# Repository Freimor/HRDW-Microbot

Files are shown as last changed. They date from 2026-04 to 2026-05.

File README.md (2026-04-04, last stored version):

# Robot Library for ESP32S3-N16R8

Библиотека функций для робота на базе микроконтроллера **ESP32S3-N16R8**.

## Компоненты

| Компонент | Модель | Интерфейс |
|---|---|---|
| Микроконтроллер | ESP32S3-N16R8 | - |
| Камера | OV5640 (DFRobot AI CAM) | DVP |
| Монитор батареи | LC709203F | I2C |
| АЦП для фоторезисторов | ADS1015 | I2C |
| Фоторезисторы | 4 шт | ADS1015 |
| Датчики линии | GP25700 (4 шт) | GPIO |
| Контроллер двигателей | DRV8834 | PWM + DIR |
| Энкодеры | OH137 (2 шт) | GPIO Interrupt |
| TOF дальномер | VL53L0X | I2C |
| Датчик освещенности | LTR-308 | I2C |
| Адресные светодиоды | SK6812 (4 шт) | GPIO |
| Buzzer | Пьезо | PWM |

## Структура проекта

```
robot-library/
├── include/
│   ├── robot_config.h      # Конфигурация пинов
│   └── robot_library.h     # Заголовочный файл библиотеки
├── src/
│   └── robot_library.cpp   # Реализация библиотеки
├── examples/
│   └── basic_example.ino   # Пример использования
└── README.md               # Этот файл
```

## Установка

1. Скопируйте папки `include` и `src` в ваш проект Arduino/PlatformIO
2. Для PlatformIO добавьте в `platformio.ini`:
   ```ini
   lib_deps = 
       pololu/vl53l0x
   build_flags = 
       -D USE_ESP_CAMERA
   ```

## Быстрый старт

```cpp
#include "robot_library.h"

void setup() {
    // Инициализация всех компонентов
    robot.begin();
}

void loop() {
    // Чтение датчиков
    float voltage = robot.getBatteryVoltage();
    uint16_t distance = robot.getDistanceMM();
    float lux = robot.getLux();
    
    // Управление двигателями
    robot.setMotorSpeed(100, 100); // Левый, Правый (-255 до 255)
    
    // Светодиоды
    robot.setAllLedsColor(255, 0, 0); // Красный цвет
    robot.showLeds();
    
    delay(1000);
}
```

## API Библиотеки

### Инициализация
- `bool begin()` - Инициализация всех компонентов

### Батарея (LC709203F)
- `float getBatteryVoltage()` - Напряжение батареи (В)
- `float getBatteryPercentage()` - Процент заряда (%)
- `bool isCharging()` - Статус зарядки

### Фоторезисторы (ADS1015)
- `PhotoResistorData getPhotoResistorData()` - Данные со всех 4 каналов
- `uint16_t getPhotoResistorValue(uint8_t channel)` - Значение канала (0-3)

### Датчики линии (GP25700)
- `LineSensorData getLineSensorData()` - Данные со всех датчиков
- `bool getLineSensorValue(uint8_t sensorNum)` - Значение датчика (1-4)
- `uint8_t getLinePosition()` - Позиция линии (0-3 или 255 если нет)

### Двигатели (DRV8834) + Энкодеры (OH137)
- `void setMotorSpeed(int16_t left, int16_t right)` - Установка скорости
- `void setLeftMotorSpeed(int16_t speed)` - Скорость левого мотора
- `void setRightMotorSpeed(int16_t speed)` - Скорость правого мотора
- `void stopMotors()` - Остановка двигателей
- `int32_t getLeftEncoderCount()` - Позиция левого энкодера
- `int32_t getRightEncoderCount()` - Позиция правого энкодера
- `void resetEncoders()` - Сброс энкодеров

### TOF дальномер (VL53L0X)
- `uint16_t getDistanceMM()` - Расстояние в мм
- `bool isDistanceValid()` - Валидность данных

### Датчик освещенности (LTR-308)
- `float getLux()` - Освещенность в Lux
- `bool isLightValid()` - Валидность данных

### Светодиоды (SK6812)
- `void setLedColor(uint8_t index, uint8_t r, uint8_t g, uint8_t b)` - Цвет светодиода
- `void setAllLedsColor(uint8_t r, uint8_t g, uint8_t b)` - Цвет всех светодиодов
- `void clearLeds()` - Выключить все
- `void showLeds()` - Обновить ленту
- `void setLedBrightness(uint8_t brightness)` - Яркость (0-255)

### Buzzer
- `void beep(uint16_t frequency, uint16_t duration_ms)` - Короткий сигнал
- `void playTone(uint16_t frequency, uint16_t duration_ms)` - Воспроизведение тона
- `void stopBuzzer()` - Остановить звук

### Камера (OV5640)
- `bool cameraInit()` - Инициализация камеры
- `bool cameraCapture()` - Захват кадра
- `void cameraDeinit()` - Деинициализация

## Конфигурация пинов

Пины настроены в файле `robot_config.h`. При необходимости измените под вашу схему.

## Зависимости

- **Arduino ESP32 Core** - базовая платформа
- **Wire.h** - I2C коммуникация (входит в core)
- **Pololu VL53L0X Library** (опционально) - для улучшенной работы TOF

## Лицензия

MIT License

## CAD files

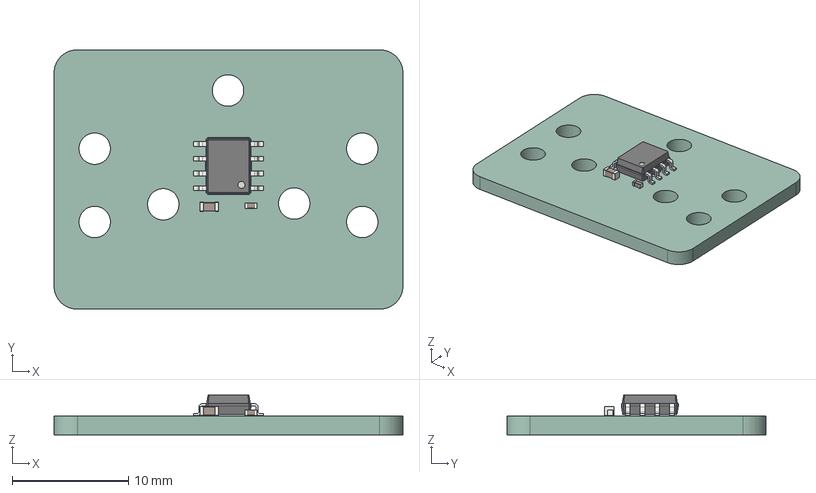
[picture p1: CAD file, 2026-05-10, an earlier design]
Old_versions/Microbot_v1/BLDC_encoder_pcb(2024-11-29_155120).step
30.0 x 22.3 x 3.40 mm
C_0603_1608Metric
SOIC_8_39x49mm_P127mm
C_0402_1005Metric
BLDC_encoder_pcb_PCB

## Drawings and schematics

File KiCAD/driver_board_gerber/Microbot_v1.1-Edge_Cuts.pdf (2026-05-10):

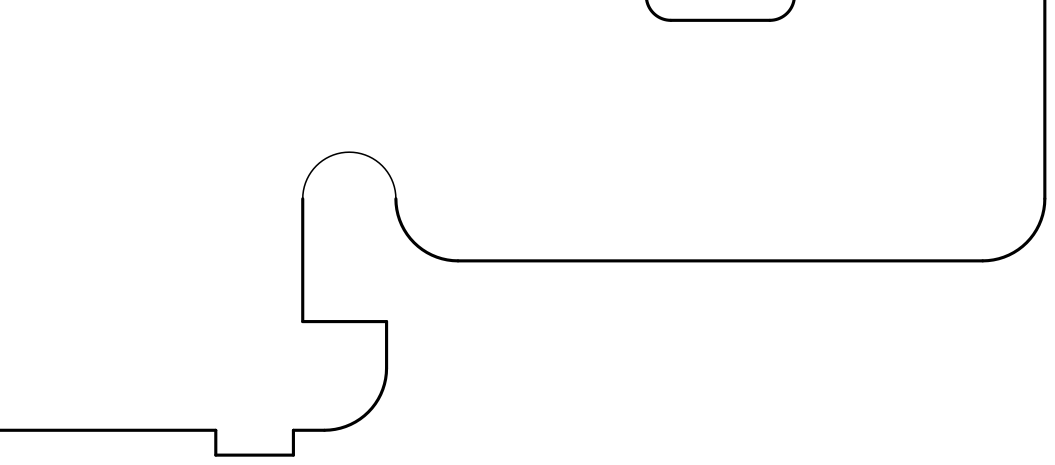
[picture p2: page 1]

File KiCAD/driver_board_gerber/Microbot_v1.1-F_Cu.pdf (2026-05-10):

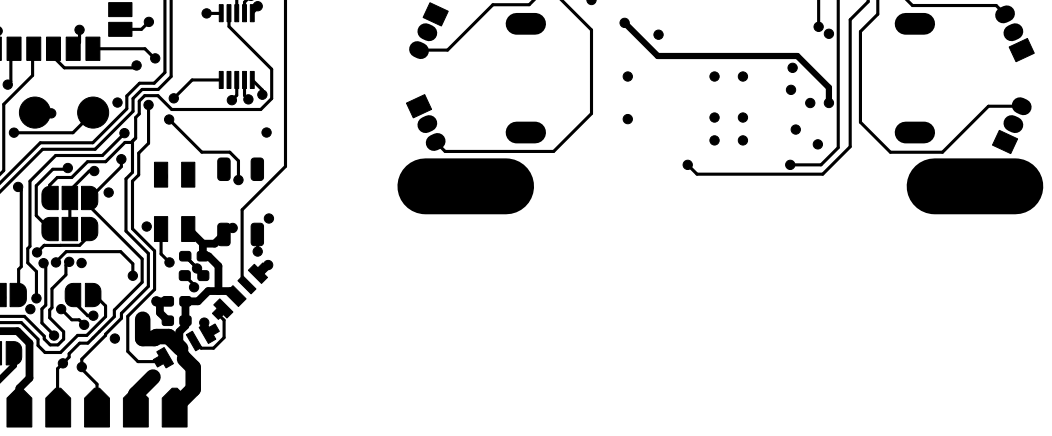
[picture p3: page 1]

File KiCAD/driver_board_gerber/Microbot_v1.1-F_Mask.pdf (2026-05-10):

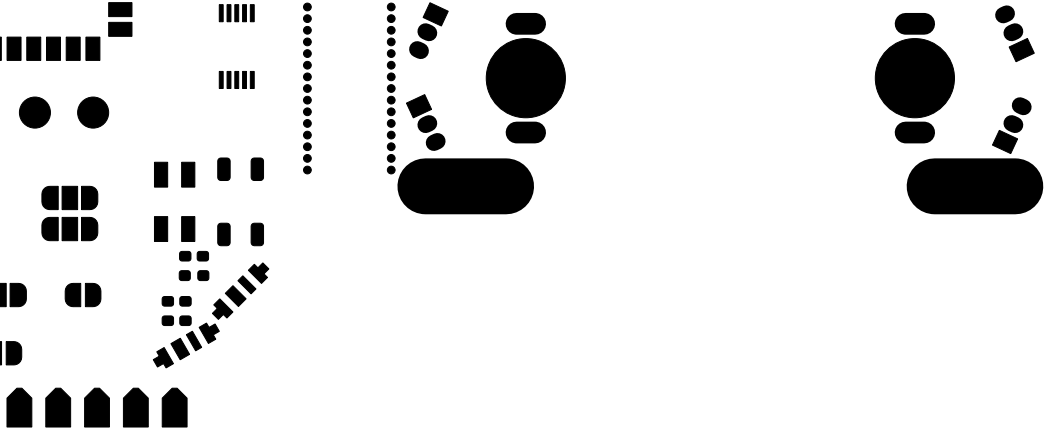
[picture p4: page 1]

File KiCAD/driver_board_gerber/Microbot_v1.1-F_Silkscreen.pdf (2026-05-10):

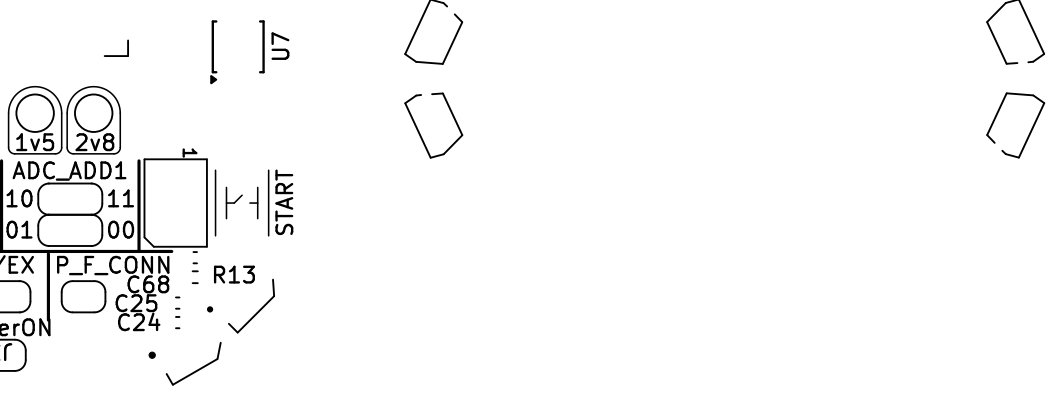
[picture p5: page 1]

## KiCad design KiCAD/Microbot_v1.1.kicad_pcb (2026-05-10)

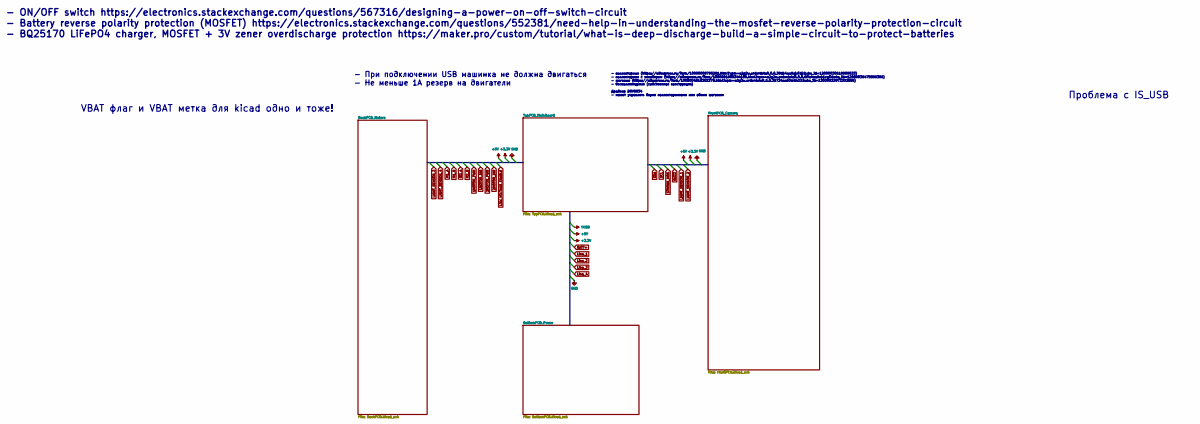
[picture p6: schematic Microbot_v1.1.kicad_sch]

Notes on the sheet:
- При подключении USB машинка не должна двигаться - Не меньше 1А резерв на двигатели
- ON/OFF switch https://electronics.stackexchange.com/questions/567316/designing-a-power-on-off-switch-circuit - Battery reverse polarity protection (MOSFET) https://electronics.stackexchange.com/questions/552381/need-help-in-understanding-the-mosfet-reverse-polarity-protection-circuit - BQ25170 Li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
Проблема с IS_USB
- коллекторные (https://aliexpress.ru/item/10000008795281.html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) - коллекторные с энкодером (https://aliexpress.ru/item/1005001608344100.html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) - шаговые (https://aliexp…
VBAT флаг и VBAT метка для kicad одно и тоже!

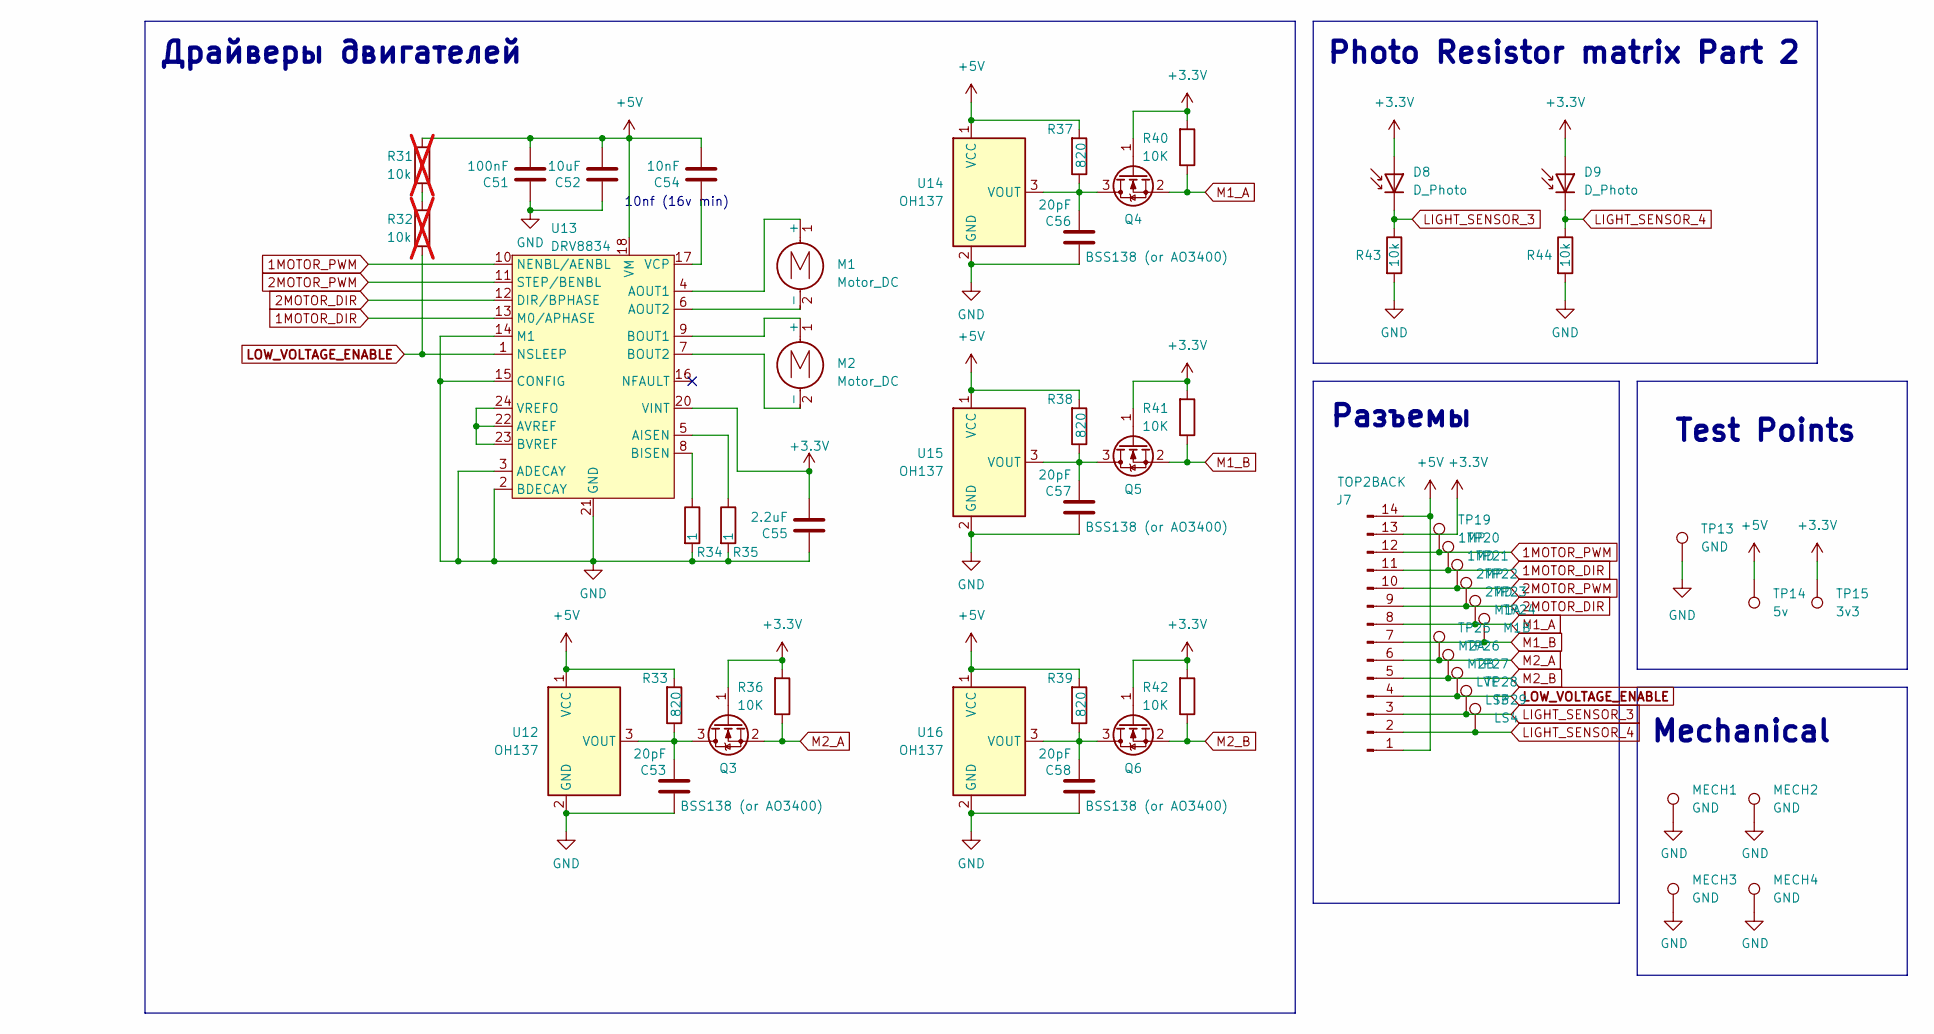
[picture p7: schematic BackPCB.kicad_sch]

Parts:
C51: 100nF; C_0402_1005Metric_Pad0.74x0.62mm_HandSolder
C52: 10uF; C_0603_1608Metric_Pad1.08x0.95mm_HandSolder
C53, C56, C57, C58: 20pF; C_0603_1608Metric_Pad1.08x0.95mm_HandSolder
C54: 10nF; C_0402_1005Metric_Pad0.74x0.62mm_HandSolder
C55: 2.2uF; C_0603_1608Metric_Pad1.08x0.95mm_HandSolder
D8, D9: D_Photo; Photoresistor_TH_Vertical
J7: TOP2BACK; CONN_14pin
M1, M2: Motor_DC; GW12-N20 with encoders PCB footprint
MECH1, MECH2, MECH3, MECH4: GND; CONN_PCB2PCB
Q3, Q4, Q5, Q6: BSS138 (or AO3400); SOT-23
R31, R32: 10k; R_0402_1005Metric_Pad0.72x0.64mm_HandSolder; not fitted
R33, R37, R38, R39: 820; R_0402_1005Metric_Pad0.72x0.64mm_HandSolder
R34, R35: 1; R_1206_3216Metric_Pad1.30x1.75mm_HandSolder
R36, R40, R41, R42: 10K; R_0402_1005Metric_Pad0.72x0.64mm_HandSolder
R43, R44: 10k; R_0402_1005Metric_Pad0.72x0.64mm_HandSolder
TP13: GND; TestPoint_Pad_D2.0mm
TP14: 5v; TestPoint_Pad_D2.0mm
TP15: 3v3; TestPoint_Pad_D2.0mm
TP19: 1MP; TestPoint_Pad_D1.0mm
TP20: 1MD; TestPoint_Pad_D1.0mm
TP21: 2MP; TestPoint_Pad_D1.0mm
TP22: 2MD; TestPoint_Pad_D1.0mm
TP23: M1A; TestPoint_Pad_D1.0mm
TP24: M1B; TestPoint_Pad_D1.0mm
TP25: M2A; TestPoint_Pad_D1.0mm
TP26: M2B; TestPoint_Pad_D1.0mm
TP27: LVE; TestPoint_Pad_D1.0mm
TP28: LS3; TestPoint_Pad_D1.0mm
TP29: LS4; TestPoint_Pad_D1.0mm
U12, U14, U15, U16: OH137; TO-92S
U13: DRV8834; HTSSOP-24-1EP_4.4x7.8mm_P0.65mm_EP3.4x7.8mm_Mask2.4x2.98mm

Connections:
1MOTOR_DIR: J7.11, TP20.1, U13.13 (M0/APHASE); also elsewhere on the board
1MOTOR_PWM: J7.12, TP19.1, U13.10 (NENBL/AENBL); also elsewhere on the board
2MOTOR_DIR: J7.9, TP22.1, U13.12 (DIR/BPHASE); also elsewhere on the board
2MOTOR_PWM: J7.10, TP21.1, U13.11 (STEP/BENBL); also elsewhere on the board
+3.3V: C55.2, D8.2 (A), D9.2 (A), J7.13, Q3.1 (G), Q4.1 (G), Q5.1 (G), Q6.1 (G), R36.2, R40.2, R41.2, R42.2, TP15.1, U13.20 (VINT); also elsewhere on the board
+5V: C51.2, C52.2, C54.2, J7.1, J7.14, R31.1, R33.2, R37.2, R38.2, R39.2, TP14.1, U12.1 (VCC), U13.18 (VM), U13.19 (VM), U14.1 (VCC), U15.1 (VCC), U16.1 (VCC); also elsewhere on the board
GND: C51.1, C52.1, C53.1, C55.1, C56.1, C57.1, C58.1, MECH1.1, MECH2.1, MECH3.1, MECH4.1, R34.2, R35.2, R43.2, R44.2, TP13.1, U12.2 (GND), U13.2 (BDECAY), U13.3 (ADECAY), U13.14 (M1), U13.15 (CONFIG), U13.21 (GND), U13.25, U14.2 (GND), U15.2 (GND), U16.2 (GND); also elsewhere on the board
LIGHT_SENSOR_3: D8.1 (K), J7.3, R43.1, TP28.1; also elsewhere on the board
LIGHT_SENSOR_4: D9.1 (K), J7.2, R44.1, TP29.1; also elsewhere on the board
LOW_VOLTAGE_ENABLE: J7.4, R32.2, TP27.1, U13.1 (NSLEEP); also elsewhere on the board
M1_A: J7.8, Q4.2 (S), R40.1, TP23.1; also elsewhere on the board
M1_B: J7.7, Q5.2 (S), R41.1, TP24.1; also elsewhere on the board
M2_A: J7.6, Q3.2 (S), R36.1, TP25.1; also elsewhere on the board
M2_B: J7.5, Q6.2 (S), R42.1, TP26.1; also elsewhere on the board
unnamed: M2.1 (+), U13.9 (BOUT1)
unnamed: M2.2 (-), U13.7 (BOUT2)
unnamed: C53.2, Q3.3 (D), R33.1, U12.3 (VOUT)
unnamed: C56.2, Q4.3 (D), R37.1, U14.3 (VOUT)
unnamed: C57.2, Q5.3 (D), R38.1, U15.3 (VOUT)
unnamed: C58.2, Q6.3 (D), R39.1, U16.3 (VOUT)
unnamed: R31.2, R32.1
unnamed: R35.1, U13.5 (AISEN)
unnamed: U13.22 (AVREF), U13.23 (BVREF), U13.24 (VREFO)
unnamed: R34.1, U13.8 (BISEN)
unnamed: C54.1, U13.17 (VCP)

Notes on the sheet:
10nf (16v min)
Photo Resistor matrix Part 2
Mechanical
Test Points
Драйверы двигателей
Разъемы

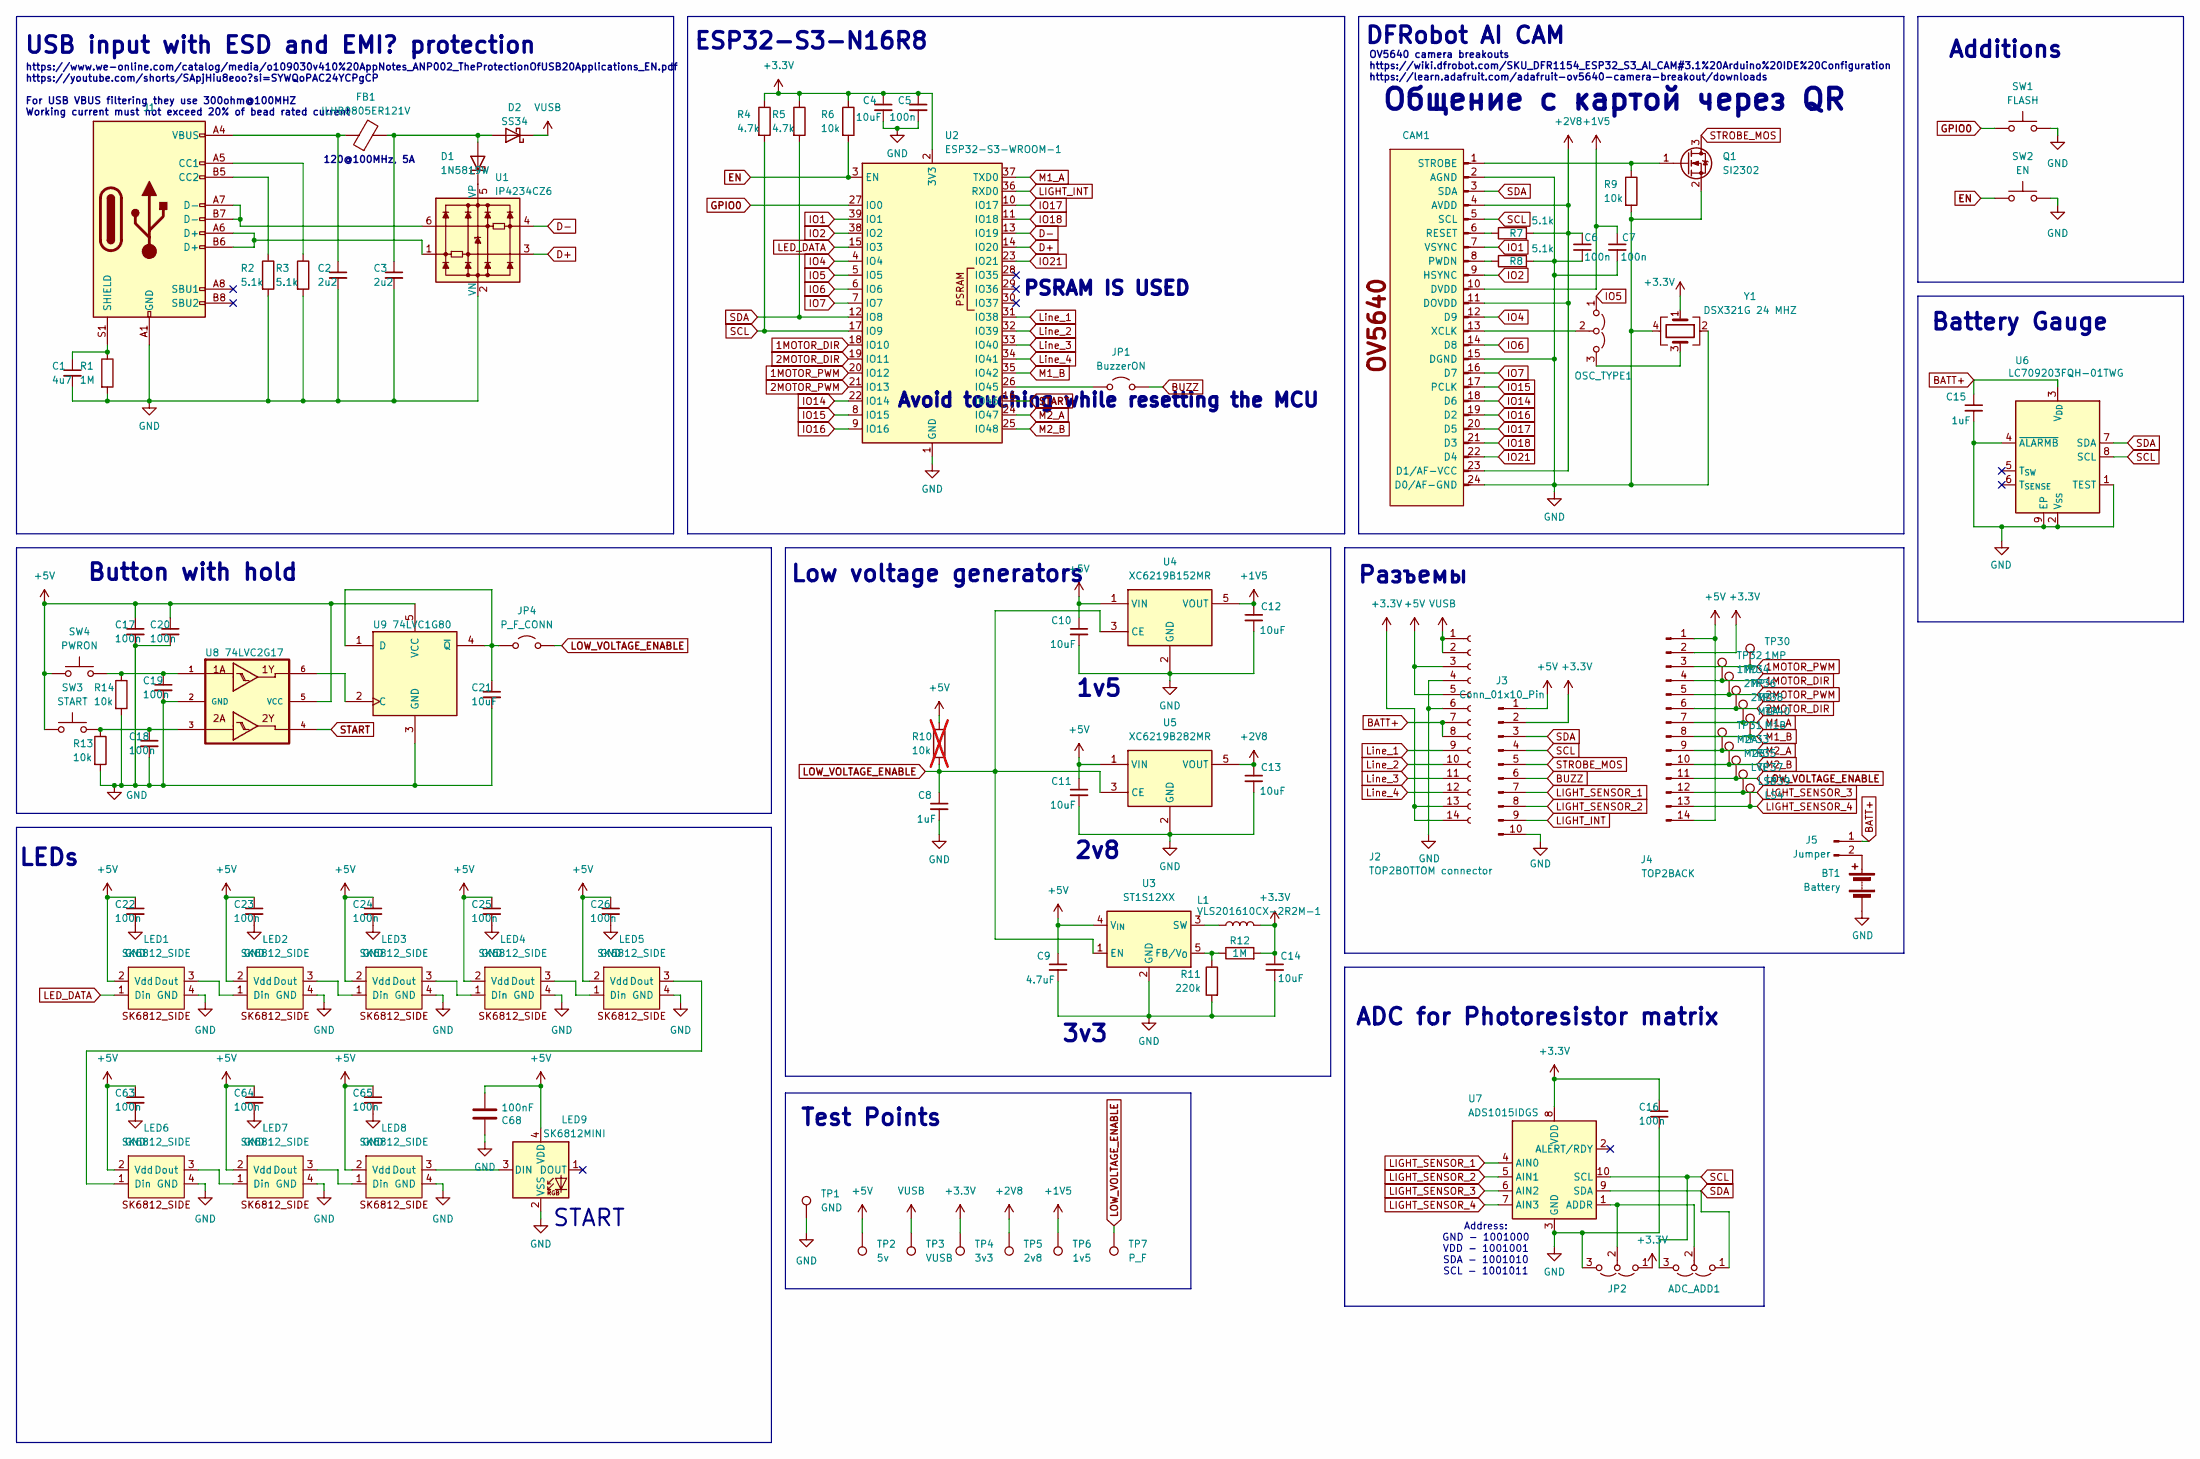
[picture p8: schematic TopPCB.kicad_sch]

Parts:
ADC_ADD1: Jumper_3_Open; SolderJumper-3_P1.3mm_Open_RoundedPad1.0x1.5mm_NumberLabels
BT1: Battery; Conn_Molex_2026560021(Pico-EZmate_Slim)
C1: 4u7; C_0603_1608Metric_Pad1.08x0.95mm_HandSolder
C2, C3: 2u2; C_0603_1608Metric_Pad1.08x0.95mm_HandSolder
C4, C21: 10uF; C_0603_1608Metric
C5, C6, C7, C16, C17, C18, C19, C20, C22, C23, C24, C25, C26, C63, C64, C65: 100n; C_0402_1005Metric_Pad0.74x0.62mm_HandSolder
C8, C15: 1uF; C_0603_1608Metric_Pad1.08x0.95mm_HandSolder
C9: 4.7uF; C_0603_1608Metric_Pad1.08x0.95mm_HandSolder
C10, C11, C12, C13, C14: 10uF; C_0603_1608Metric_Pad1.08x0.95mm_HandSolder
C68: 100nF; C_0402_1005Metric_Pad0.74x0.62mm_HandSolder
CAM1: OV5640; CAM_OV5640_OMRON_XF2M-2415-1A
D1: 1N5819W; D_SOD-123
D2: SS34; D_SMA_Handsoldering
FB1: ILHB0805ER121V; L_0805_2012Metric_Pad1.15x1.40mm_HandSolder
J1: USB_C_Receptacle_USB2.0; RUICHI_TYPE-C-16PF-020
J2: TOP2BOTTOM connector; PinHeader_2x07_P2.54mm_Vertical_SMD
J3: Conn_01x10_Pin; CONN_10pin
J4: TOP2BACK; CONN_14pin
J5: Jumper; PinHeader_1x02_P2.54mm_Vertical
JP1: BuzzerON; SolderJumper-2_P1.3mm_Open_RoundedPad1.0x1.5mm
JP2: Jumper_3_Open; SolderJumper-3_P1.3mm_Open_RoundedPad1.0x1.5mm_NumberLabels
JP4: P_F_CONN; SolderJumper-2_P1.3mm_Open_RoundedPad1.0x1.5mm
L1: VLS201610CX-2R2M-1; IND_VLS201610CX-220M-1
LED1, LED2, LED3, LED4, LED5, LED6, LED7, LED8: SK6812_SIDE; ADR_LED_SK6812_SIDE
LED9: SK6812MINI; LED_SK6812MINI_PLCC4_3.5x3.5mm_P1.75mm
OSC_TYPE1: OSC_IN/EX; SolderJumper-3_P1.3mm_Open_RoundedPad1.0x1.5mm_NumberLabels
Q1: SI2302; SOT-23
R1, R12: 1M; R_0402_1005Metric_Pad0.72x0.64mm_HandSolder
R2, R3, R7, R8: 5.1k; R_0402_1005Metric_Pad0.72x0.64mm_HandSolder
R4, R5: 4.7k; R_0402_1005Metric_Pad0.72x0.64mm_HandSolder
R6, R9, R13, R14: 10k; R_0402_1005Metric_Pad0.72x0.64mm_HandSolder
R10: 10k; R_0402_1005Metric_Pad0.72x0.64mm_HandSolder; not fitted
R11: 220k; R_0402_1005Metric_Pad0.72x0.64mm_HandSolder
SW1: FLASH; SW_SMD_KLS7-TS3401
SW2: EN; SW_SMD_KLS7-TS3401
SW3: START; SW_SMD_KLS7-TS3401
SW4: PWRON; SW_SMD_KLS7-TS3401
TP1: GND; TestPoint_Pad_D2.0mm
TP2: 5v; TestPoint_Pad_D2.0mm
TP3: VUSB; TestPoint_Pad_D2.0mm
TP4: 3v3; TestPoint_Pad_D2.0mm
TP5: 2v8; TestPoint_Pad_D2.0mm
TP6: 1v5; TestPoint_Pad_D2.0mm
TP7: P_F; TestPoint_Pad_D2.0mm
TP30: 1MP; TestPoint_Pad_D1.0mm
TP31: M2A; TestPoint_Pad_D1.0mm
TP32: 1MD; TestPoint_Pad_D1.0mm
TP33: M2B; TestPoint_Pad_D1.0mm
TP34: 2MP; TestPoint_Pad_D1.0mm
TP35: LVE; TestPoint_Pad_D1.0mm
TP36: 2MD; TestPoint_Pad_D1.0mm
TP37: LS3; TestPoint_Pad_D1.0mm
TP38: M1A; TestPoint_Pad_D1.0mm
TP39: LS4; TestPoint_Pad_D1.0mm
TP40: M1B; TestPoint_Pad_D1.0mm
U1: IP4234CZ6; SC-74-6_1.55x2.9mm_P0.95mm
U2: ESP32-S3-WROOM-1
U3: ST1S12XX; TSOT-23-5
U4: XC6219B152MR; SOT-23-5
U5: XC6219B282MR; SOT-23-5
U6: LC709203FQH-01TWG; WDFN-8-1EP_4x3mm_P0.65mm_EP2.4x1.8mm
U7: ADS1015IDGS; TSSOP-10_3x3mm_P0.5mm
U8: 74LVC2G17; SOT-23-6_Handsoldering
U9: 74LVC1G80
Y1: DSX321G 24 MHZ; Crystal_SMD_3225-4Pin_3.2x2.5mm_HandSoldering

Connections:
1MOTOR_DIR: J4.4, TP32.1, U2.18 (IO10); also elsewhere on the board
1MOTOR_PWM: J4.3, TP30.1, U2.20 (IO12); also elsewhere on the board
2MOTOR_DIR: J4.6, TP36.1, U2.19 (IO11); also elsewhere on the board
2MOTOR_PWM: J4.5, TP34.1, U2.21 (IO13); also elsewhere on the board
+1V5: C7.1, C12.1, CAM1.10 (DVDD), TP6.1, U4.5 (VOUT)
+2V8: C6.1, C13.1, CAM1.4 (AVDD), CAM1.11 (DOVDD), CAM1.23 (D1/AF-VCC), R7.2, TP5.1, U5.5 (VOUT)
+3.3V: C4.1, C5.1, C14.1, C16.1, J2.13, J2.14, J3.2, J4.2, JP2.1 (A), L1.2, R4.1, R5.1, R6.1, R12.2, TP4.1, U2.2 (3V3), U7.8 (VDD), Y1.1; also elsewhere on the board
+5V: C9.1, C10.1, C11.1, C17.1, C20.1, C22.1, C23.1, C24.1, C25.1, C26.1, C63.1, C64.1, C65.1, C68.2, J2.3, J2.5, J3.1, J4.1, J4.14, LED1.2 (Vdd), LED2.2 (Vdd), LED3.2 (Vdd), LED4.2 (Vdd), LED5.2 (Vdd), LED6.2 (Vdd), LED7.2 (Vdd), LED8.2 (Vdd), LED9.4 (VDD), R10.1, SW3.1, SW4.1, TP2.1, U3.4 (V_{IN}), U4.1 (VIN), U5.1 (VIN), U8.5 (VCC), U9.5 (VCC); also elsewhere on the board
BATT+: C15.1, J2.7, J2.8, J5.1, U6.3 (V_{DD}); also elsewhere on the board
BUZZ: J3.6, JP1.2 (B); also elsewhere on the board
D+: U1.3, U2.14 (IO20)
D-: U1.4, U2.13 (IO19)
EN: R6.2, SW2.1, U2.3 (EN)
GND: BT1.2 (-), C1.2, C2.2, C3.2, C4.2, C5.2, C6.2, C7.2, C8.2, C9.2, C10.2, C11.2, C12.2, C13.2, C14.2, C15.2, C16.2, C17.2, C18.2, C19.2, C20.2, C21.2, C22.2, C23.2, C24.2, C25.2, C26.2, C63.2, C64.2, C65.2, C68.1, CAM1.2 (AGND), CAM1.15 (DGND), CAM1.24 (D0/AF-GND), CAM1.P1, CAM1.P2, J1.A1 (GND), J1.A12 (GND), J1.B1 (GND), J1.B12 (GND), J2.4, J2.6, J3.10, JP2.3 (B), LED1.4 (GND), LED2.4 (GND), LED3.4 (GND), LED4.4 (GND), LED5.4 (GND), LED6.4 (GND), LED7.4 (GND), LED8.4 (GND), LED9.2 (VSS), Q1.2 (S), R1.2, R2.2, R3.2, R8.2, R9.2, R11.2, R13.2, R14.2, SW1.2, SW2.2, TP1.1, U1.2 (VN), U2.1 (GND), U2.40 (GND), U2.41 (GND), U3.2 (GND), U4.2 (GND), U5.2 (GND), U6.1 (TEST), U6.2 (V_{SS}), U6.4 (~ALARMB), U6.9 (EP), U7.3 (GND), U8.2 (GND), U9.3 (GND), Y1.2, Y1.4; also elsewhere on the board
GPIO0: SW1.1, U2.27 (IO0)
IO1: CAM1.7 (VSYNC), U2.39 (IO1)
IO2: CAM1.9 (HSYNC), U2.38 (IO2)
IO4: CAM1.12 (D9), U2.4 (IO4)
IO5: OSC_TYPE1.1 (A), U2.5 (IO5)
IO6: CAM1.14 (D8), U2.6 (IO6)
IO7: CAM1.16 (D7), U2.7 (IO7)
IO14: CAM1.18 (D6), U2.22 (IO14)
IO15: CAM1.17 (PCLK), U2.8 (IO15)
IO16: CAM1.19 (D2), U2.9 (IO16)
IO17: CAM1.20 (D5), U2.10 (IO17)
IO18: CAM1.21 (D3), U2.11 (IO18)
IO21: CAM1.22 (D4), U2.23 (IO21)
LED_DATA: LED1.1 (Din), U2.15 (IO3)
LIGHT_INT: J3.9, U2.36 (RXD0); also elsewhere on the board
LIGHT_SENSOR_1: J3.7, U7.4 (AIN0); also elsewhere on the board
LIGHT_SENSOR_2: J3.8, U7.5 (AIN1); also elsewhere on the board
LIGHT_SENSOR_3: J4.12, TP37.1, U7.6 (AIN2); also elsewhere on the board
LIGHT_SENSOR_4: J4.13, TP39.1, U7.7 (AIN3); also elsewhere on the board
LOW_VOLTAGE_ENABLE: C8.1, J4.11, JP4.2 (B), R10.2, TP7.1, TP35.1, U3.1 (EN), U4.3 (CE), U5.3 (CE); also elsewhere on the board
Line_1: J2.9, U2.31 (IO38); also elsewhere on the board
Line_2: J2.10, U2.32 (IO39); also elsewhere on the board
Line_3: J2.11, U2.33 (IO40); also elsewhere on the board
Line_4: J2.12, U2.34 (IO41); also elsewhere on the board
M1_A: J4.7, TP38.1, U2.37 (TXD0); also elsewhere on the board
M1_B: J4.8, TP40.1, U2.35 (IO42); also elsewhere on the board
M2_A: J4.9, TP31.1, U2.24 (IO47); also elsewhere on the board
M2_B: J4.10, TP33.1, U2.25 (IO48); also elsewhere on the board
unnamed: ADC_ADD1.2 (C), JP2.2 (C), U7.1 (ADDR)
unnamed: BT1.1 (+), J5.2
unnamed: C2.1, FB1.1, J1.A4 (VBUS), J1.A9 (VBUS), J1.B4 (VBUS), J1.B9 (VBUS)
unnamed: C18.1, R13.1, SW3.2, U8.3
unnamed: C19.1, R14.1, SW4.2, U8.1
unnamed: CAM1.8 (PWDN), R8.1
unnamed: CAM1.6 (RESET), R7.1
unnamed: CAM1.1 (STROBE), Q1.1 (G), R9.1
unnamed: CAM1.13 (XCLK), OSC_TYPE1.2 (C)
unnamed: C3.1, D1.2 (A), D2.2 (A), FB1.2
unnamed: D1.1 (K), U1.5 (VP)
unnamed: J1.A5 (CC1), R3.1
unnamed: J1.B5 (CC2), R2.1
unnamed: J1.A6 (D+), J1.B6 (D+), U1.1
unnamed: J1.A7 (D-), J1.B7 (D-), U1.6
unnamed: C1.1, J1.S1 (SHIELD), R1.1
unnamed: JP1.1 (A), U2.26 (IO45)
unnamed: C21.1, JP4.1 (A), U9.1 (D), U9.4 (~Q)
unnamed: LED1.3 (Dout), LED2.1 (Din)
unnamed: LED2.3 (Dout), LED3.1 (Din)
unnamed: LED3.3 (Dout), LED4.1 (Din)
unnamed: LED4.3 (Dout), LED5.1 (Din)
unnamed: LED5.3 (Dout), LED6.1 (Din)
unnamed: LED6.3 (Dout), LED7.1 (Din)
unnamed: LED7.3 (Dout), LED8.1 (Din)
unnamed: LED8.3 (Dout), LED9.3 (DIN)
unnamed: OSC_TYPE1.3 (B), Y1.3
unnamed: R11.1, R12.1, U3.5 (FB/V_{O})
unnamed: L1.1, U3.3 (SW)
unnamed: U8.6, U9.2 (C)
SCL: ADC_ADD1.3 (B), CAM1.5 (SCL), J3.4, R4.2, U2.17 (IO9), U6.8 (SCL), U7.10 (SCL); also elsewhere on the board
SDA: ADC_ADD1.1 (A), CAM1.3 (SDA), J3.3, R5.2, U2.12 (IO8), U6.7 (SDA), U7.9 (SDA); also elsewhere on the board
START: U2.16 (IO46), U8.4
STROBE_MOS: J3.5, Q1.3 (D); also elsewhere on the board
VUSB: D2.1 (K), J2.1, J2.2, TP3.1; also elsewhere on the board

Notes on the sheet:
ADC for Photoresistor matrix
LEDs
120@100MHz, 5A
Общение с картой через QR
Avoid touching while resetting the MCU
Разъемы
OV5640 camera breakouts https://wiki.dfrobot.com/SKU_DFR1154_ESP32_S3_AI_CAM#3.1%20Arduino%20IDE%20Configuration https://learn.adafruit.com/adafruit-ov5640-camera-breakout/downloads
DFRobot AI CAM
Test Points
3v3
2v8
PSRAM IS USED
1v5
Low voltage generators
START
Button with hold
Battery Gauge
Additions
https://www.we-online.com/catalog/media/o109030v410%20AppNotes_ANP002_TheProtectionOfUSB20Applications_EN.pdf https://youtube.com/shorts/SApjHiu8eoo?si=SYWQoPAC24YCPgCP For USB VBUS filtering they use 300ohm@100MHZ Working current must not exceed 20% of bead rated current
USB input with ESD and EMI? protection
ESP32-S3-N16R8
Address: GND - 1001000 VDD - 1001001 SDA - 1001010 SCL - 1001011

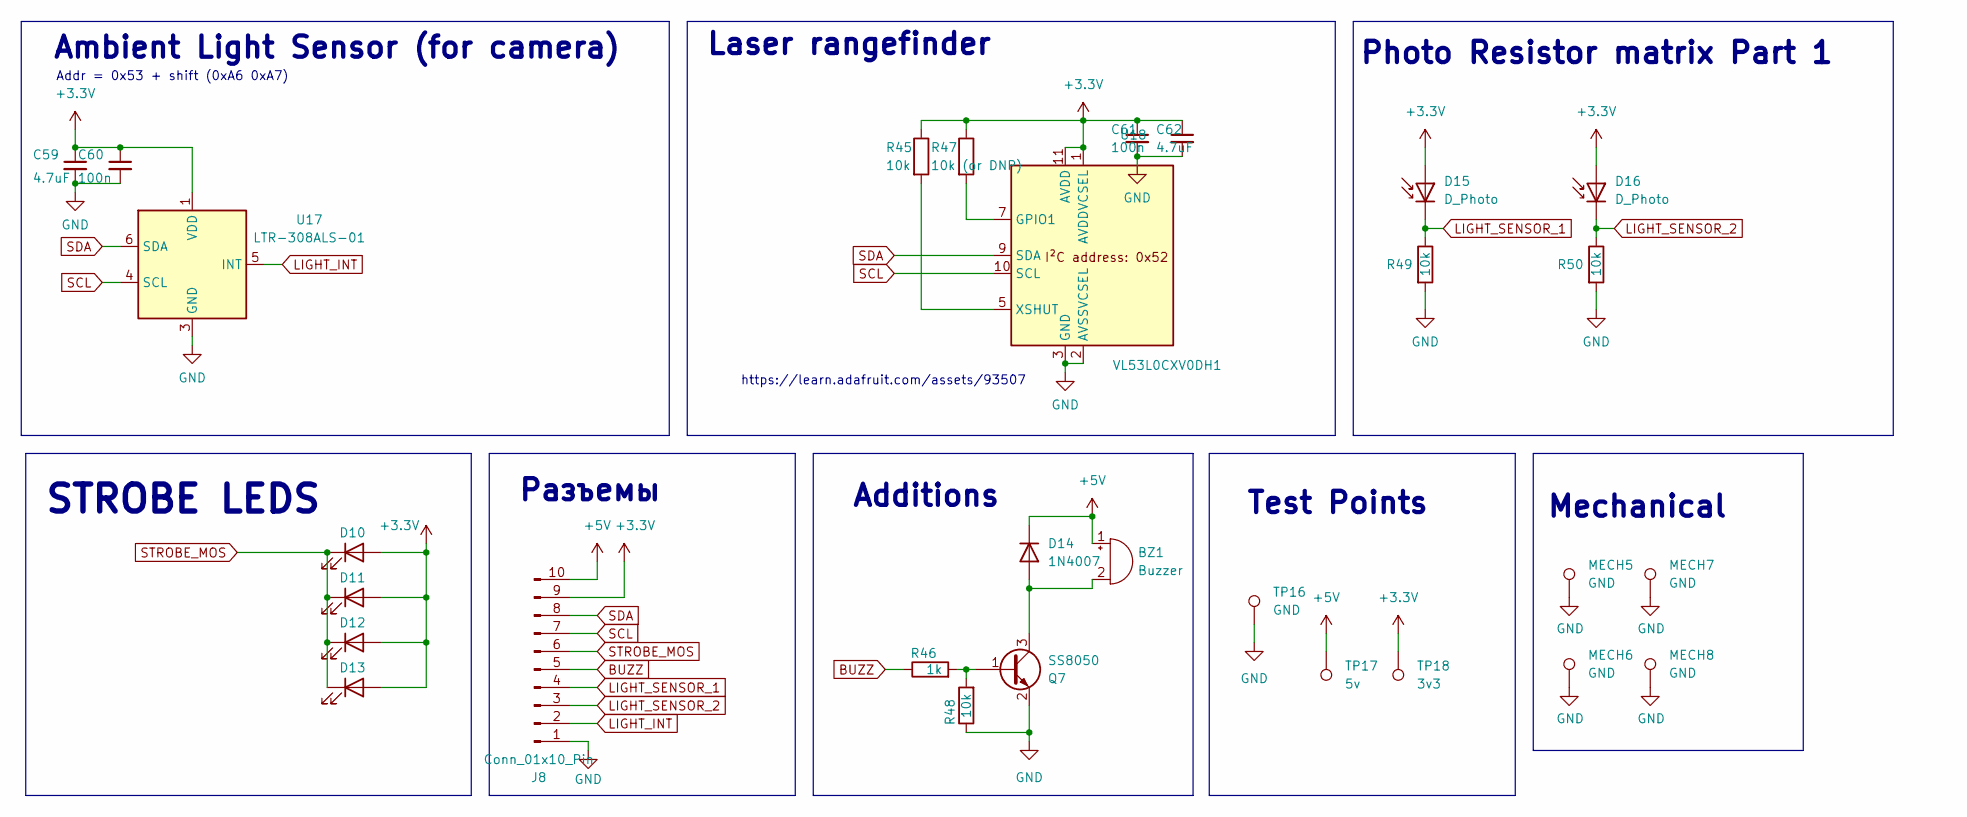
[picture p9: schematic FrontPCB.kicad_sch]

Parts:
BZ1: Buzzer; PASSIVE_SMD_MLT-8530
C59, C62: 4.7uF; C_0603_1608Metric
C60, C61: 100n; C_0402_1005Metric_Pad0.74x0.62mm_HandSolder
D10, D11, D12, D13: HL-A-2835H358W-2-S1-08L-HR3; LED_Everlight-SMD3528_3.5x2.8mm_67-21ST
D14: 1N4007; D_SOD-123F
D15, D16: D_Photo; Photoresistor_TH_Vertical
J8: Conn_01x10_Pin; CONN_10pin
MECH5, MECH6, MECH7, MECH8: GND; CONN_PCB2PCB
Q7: SS8050; SOT-23
R45, R48, R49, R50: 10k; R_0402_1005Metric_Pad0.72x0.64mm_HandSolder
R46: 1k; R_0402_1005Metric_Pad0.72x0.64mm_HandSolder
R47: 10k (or DNP); R_0402_1005Metric_Pad0.72x0.64mm_HandSolder
TP16: GND; TestPoint_Pad_D2.0mm
TP17: 5v; TestPoint_Pad_D2.0mm
TP18: 3v3; TestPoint_Pad_D2.0mm
U17: LTR-308ALS-01; LightSensor_LTR-303ALS-01
U18: VL53L0CXV0DH1; ToF_LaserRange_VL53L0X_StandartFootprint

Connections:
+3.3V: C59.1, C60.1, C61.1, C62.1, D10.2 (A), D11.2 (A), D12.2 (A), D13.2 (A), D15.2 (A), D16.2 (A), J8.9, R45.1, R47.1, TP18.1, U17.1 (VDD), U18.1 (AVDDVCSEL), U18.11 (AVDD); also elsewhere on the board
+5V: BZ1.1 (-), D14.1 (K), J8.10, TP17.1; also elsewhere on the board
BUZZ: J8.5, R46.1; also elsewhere on the board
GND: C59.2, C60.2, C61.2, C62.2, J8.1, MECH5.1, MECH6.1, MECH7.1, MECH8.1, Q7.2 (E), R48.1, R49.2, R50.2, TP16.1, U17.3 (GND), U18.2 (AVSSVCSEL), U18.3 (GND), U18.4 (GND), U18.6 (GND), U18.12 (GND); also elsewhere on the board
LIGHT_INT: J8.2, U17.5 (INT); also elsewhere on the board
LIGHT_SENSOR_1: D15.1 (K), J8.4, R49.1; also elsewhere on the board
LIGHT_SENSOR_2: D16.1 (K), J8.3, R50.1; also elsewhere on the board
unnamed: BZ1.2 (+), D14.2 (A), Q7.3 (C)
unnamed: Q7.1 (B), R46.2, R48.2
unnamed: R47.2, U18.7 (GPIO1)
unnamed: R45.2, U18.5 (XSHUT)
SCL: J8.7, U17.4 (SCL), U18.10 (SCL); also elsewhere on the board
SDA: J8.8, U17.6 (SDA), U18.9 (SDA); also elsewhere on the board
STROBE_MOS: D10.1 (K), D11.1 (K), D12.1 (K), D13.1 (K), J8.6; also elsewhere on the board

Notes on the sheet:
Mechanical
Test Points
Photo Resistor matrix Part 1
STROBE LEDS
Laser rangefinder
Ambient Light Sensor (for camera)
Addr = 0x53 + shift (0xA6 0xA7)
Additions
Разъемы
https://learn.adafruit.com/assets/93507

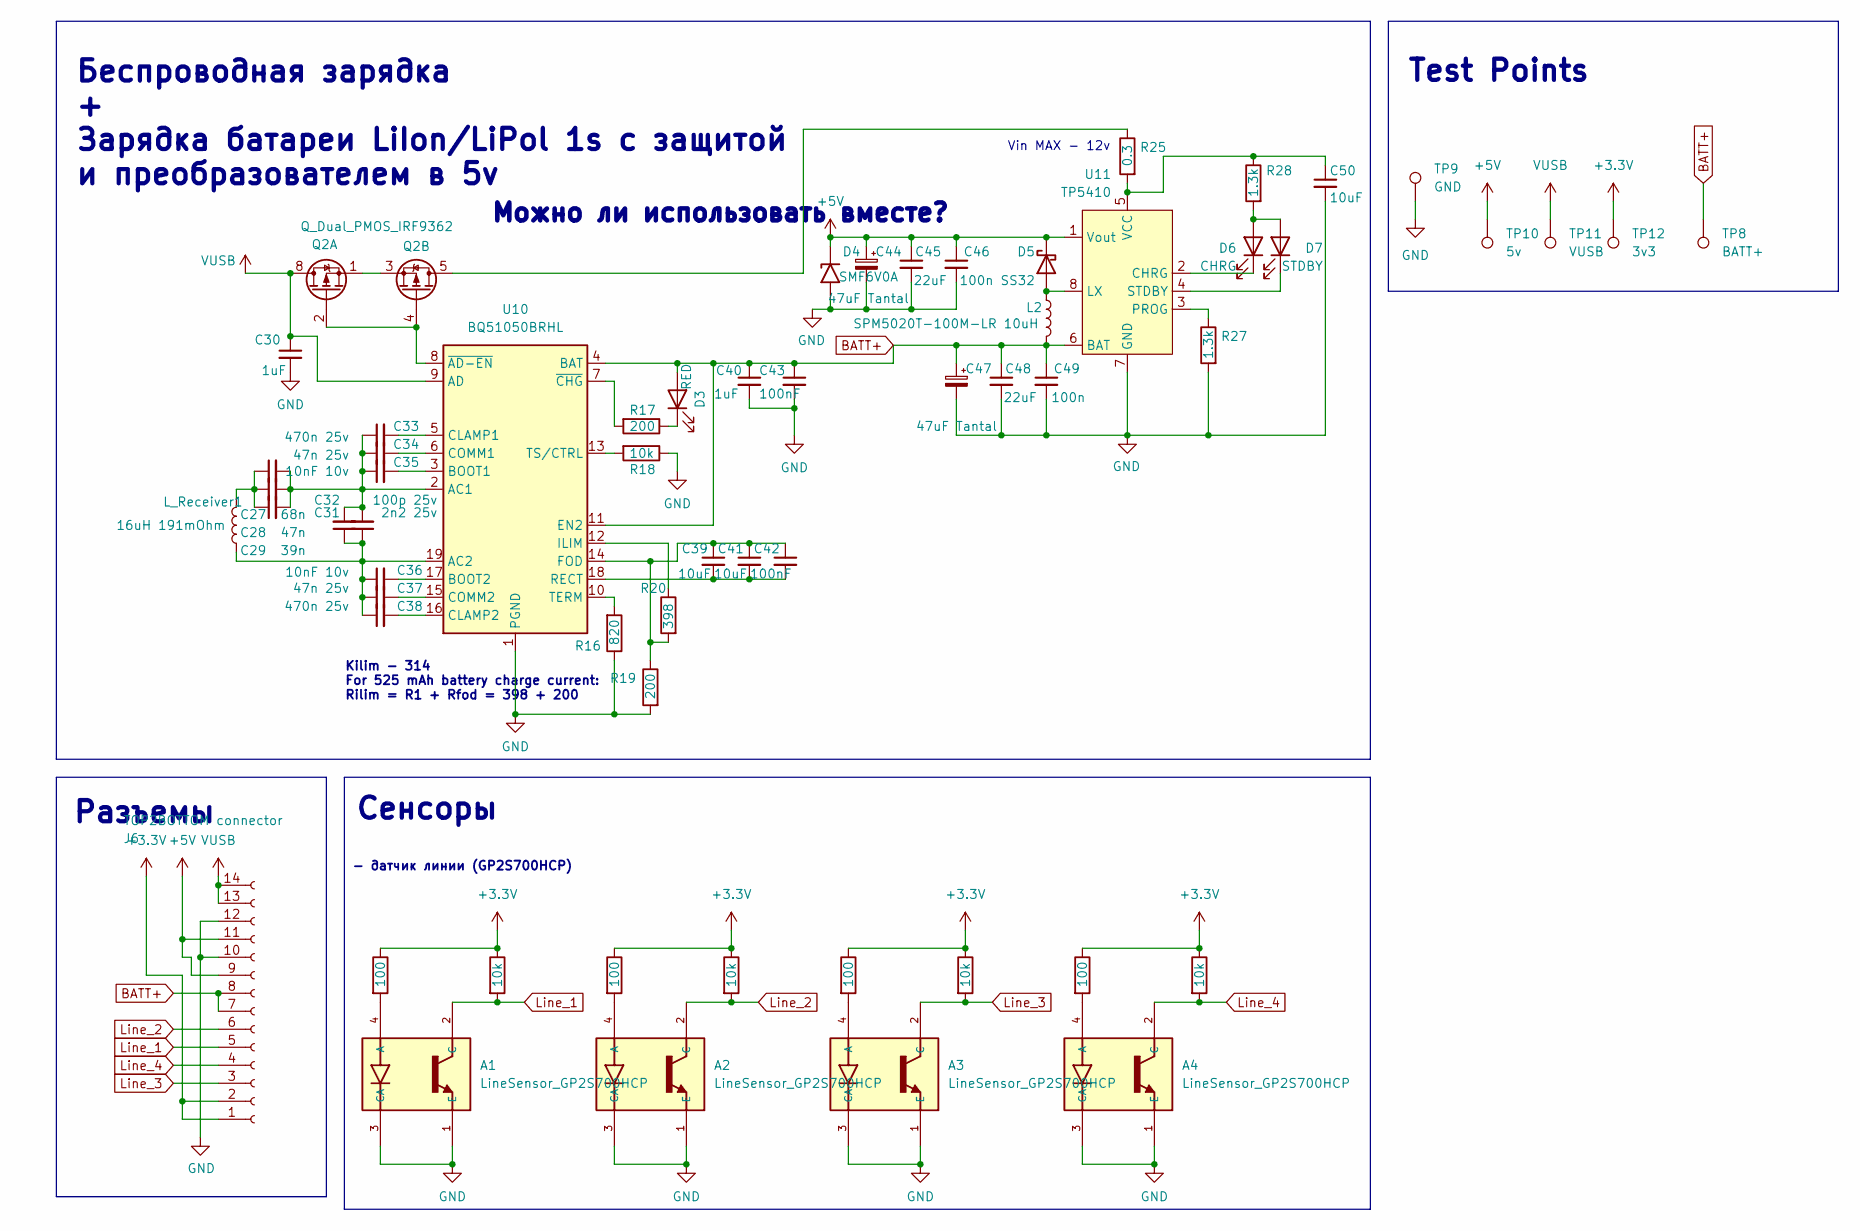
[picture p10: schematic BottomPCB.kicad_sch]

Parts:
A1, A2, A3, A4: LineSensor_GP2S700HCP; GP2S700HCP; PARTREV Oct. 3. 2005
C27: 68n; C_0402_1005Metric_Pad0.74x0.62mm_HandSolder
C28: 47n; C_0402_1005Metric_Pad0.74x0.62mm_HandSolder
C29: 39n; C_0402_1005Metric_Pad0.74x0.62mm_HandSolder
C30: 1uF; C_0603_1608Metric_Pad1.08x0.95mm_HandSolder
C31: 2n2 25v; C_0402_1005Metric_Pad0.74x0.62mm_HandSolder
C32: 100p 25v; C_0402_1005Metric_Pad0.74x0.62mm_HandSolder
C33, C38: 470n 25v; C_0402_1005Metric_Pad0.74x0.62mm_HandSolder
C34, C37: 47n 25v; C_0402_1005Metric_Pad0.74x0.62mm_HandSolder
C35, C36: 10nF 10v; C_0402_1005Metric_Pad0.74x0.62mm_HandSolder
C39, C41: 10uF; C_0603_1608Metric
C40: 1uF; C_0603_1608Metric
C42, C43: 100nF; C_0402_1005Metric_Pad0.74x0.62mm_HandSolder
C44, C47: 47uF Tantal; CP_EIA-7343-31_Kemet-D
C45, C48: 22uF; C_0805_2012Metric_Pad1.18x1.45mm_HandSolder
C46, C49: 100n; C_0402_1005Metric_Pad0.74x0.62mm_HandSolder
C50: 10uF; C_0603_1608Metric_Pad1.08x0.95mm_HandSolder
D3: RED; LED_SIDE_KA-2810_Kingbright
D4: SMF6V0A; D_SOD-123F
D5: SS32; D_SMA-SMB_Universal_Handsoldering
D6: CHRG; LED_SIDE_KA-2810_Kingbright
D7: STDBY; LED_SIDE_KA-2810_Kingbright
J6: TOP2BOTTOM connector; PinHeader_2x07_P2.54mm_Vertical_SMD
L2: SPM5020T-100M-LR 10uH; INDUCTOR_SPM5020T
L_Receiver1: 16uH 191mOhm; COIL
Q2: Q_Dual_PMOS_IRF9362; SOP-8_3.76x4.96mm_P1.27mm
R15, R22, R24, R29: 100; R_0805_2012Metric_Pad1.20x1.40mm_HandSolder
R16: 820; R_0402_1005Metric_Pad0.72x0.64mm_HandSolder
R17, R19: 200; R_0402_1005Metric_Pad0.72x0.64mm_HandSolder
R18, R21, R23, R26, R30: 10k; R_0402_1005Metric_Pad0.72x0.64mm_HandSolder
R20: 398; R_0402_1005Metric_Pad0.72x0.64mm_HandSolder
R25: 0.3; R_1210_3225Metric_Pad1.30x2.65mm_HandSolder
R27, R28: 1.3k; R_0402_1005Metric_Pad0.72x0.64mm_HandSolder
TP8: BATT+; TestPoint_Pad_D2.0mm
TP9: GND; TestPoint_Pad_D2.0mm
TP10: 5v; TestPoint_Pad_D2.0mm
TP11: VUSB; TestPoint_Pad_D2.0mm
TP12: 3v3; TestPoint_Pad_D2.0mm
U10: BQ51050BRHL; Texas_VQFN-RHL-20
U11: TP5410

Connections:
+3.3V: J6.1, J6.2, R15.1, R21.1, R22.1, R23.1, R24.1, R26.1, R29.1, R30.1, TP12.1; also elsewhere on the board
+5V: C44.1, C45.1, C46.1, D4.1 (A1), D5.1 (K), J6.9, J6.11, TP10.1, U11.1 (Vout); also elsewhere on the board
BATT+: C40.1, C43.1, C47.1, C48.1, C49.1, D3.2 (A), J6.7, J6.8, L2.1, TP8.1, U10.4 (BAT), U10.11 (EN2), U11.6 (BAT); also elsewhere on the board
GND: A1.1 (E), A1.3 (CA), A2.1 (E), A2.3 (CA), A3.1 (E), A3.3 (CA), A4.1 (E), A4.3 (CA), C30.2, C40.2, C43.2, C44.2, C45.2, C46.2, C47.2, C48.2, C49.2, C50.2, D4.2 (A2), J6.10, J6.12, R16.1, R18.1, R19.2, R27.2, TP9.1, U10.1 (PGND), U10.20 (PGND), U10.21 (PGND), U11.7 (GND), U11.9; also elsewhere on the board
Line_1: A1.2 (C), J6.5, R21.2; also elsewhere on the board
Line_2: A2.2 (C), J6.6, R23.2; also elsewhere on the board
Line_3: A3.2 (C), J6.3, R26.2; also elsewhere on the board
Line_4: A4.2 (C), J6.4, R30.2; also elsewhere on the board
unnamed: A1.4 (A), R15.2
unnamed: A2.4 (A), R22.2
unnamed: A3.4 (A), R24.2
unnamed: A4.4 (A), R29.2
unnamed: C27.1, C28.1, C29.1, L_Receiver1.2
unnamed: D3.1 (K), R17.1
unnamed: D5.2 (A), L2.2, U11.8 (LX)
unnamed: D6.2 (A), D7.2 (A), R28.2
unnamed: D6.1 (K), U11.2 (CHRG)
unnamed: D7.1 (K), U11.4 (STDBY)
unnamed: Q2.2 (G), Q2.4 (G), U10.8 (~AD-EN)
unnamed: Q2.1 (S), Q2.3 (S)
unnamed: Q2.5 (D), Q2.6 (D), R25.1
unnamed: C27.2, C28.2, C29.2, C31.2, C32.2, C33.1, C34.1, C35.1, U10.2 (AC1)
unnamed: C31.1, C32.1, C36.1, C37.1, C38.1, L_Receiver1.1, U10.19 (AC2)
unnamed: C35.2, U10.3 (BOOT1)
unnamed: C36.2, U10.17 (BOOT2)
unnamed: C33.2, U10.5 (CLAMP1)
unnamed: C38.2, U10.16 (CLAMP2)
unnamed: C34.2, U10.6 (COMM1)
unnamed: C37.2, U10.15 (COMM2)
unnamed: C39.1, C41.1, C42.1, R19.1, R20.2, U10.14 (FOD)
unnamed: R20.1, U10.12 (ILIM)
unnamed: C39.2, C41.2, C42.2, U10.18 (RECT)
unnamed: R16.2, U10.10 (TERM)
unnamed: R18.2, U10.13 (TS/CTRL)
unnamed: R17.2, U10.7 (~CHG)
unnamed: R27.1, U11.3 (PROG)
unnamed: C50.1, R25.2, R28.1, U11.5 (VCC)
VUSB: C30.1, J6.13, J6.14, Q2.7 (D), Q2.8 (D), TP11.1, U10.9 (AD); also elsewhere on the board

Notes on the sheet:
- датчик линии (GP2S700HCP)
Беспроводная зарядка + Зарядка батареи LiIon/LiPol 1s с защитой и преобразователем в 5v
Test Points
Можно ли использовать вместе?
Сенсоры
Kilim - 314 For 525 mAh battery charge current: Rilim = R1 + Rfod = 398 + 200
Разъемы
Vin MAX - 12v

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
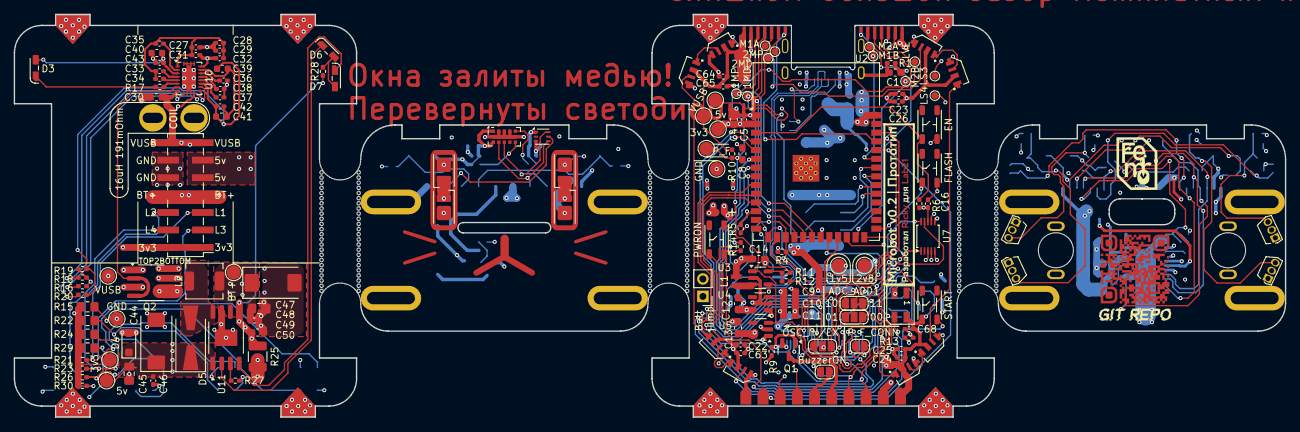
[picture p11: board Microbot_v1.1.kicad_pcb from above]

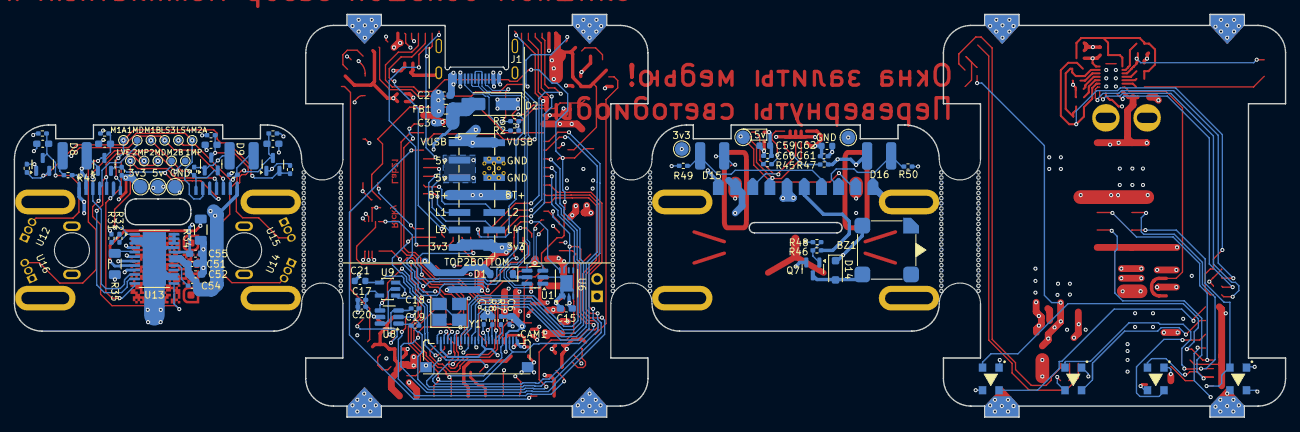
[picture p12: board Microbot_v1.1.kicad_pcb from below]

Board: 4 copper layers, 185.0 x 58.6 mm, 246 parts (92 on the bottom side), 123 nets.

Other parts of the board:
Ref**: Val**; Graphic

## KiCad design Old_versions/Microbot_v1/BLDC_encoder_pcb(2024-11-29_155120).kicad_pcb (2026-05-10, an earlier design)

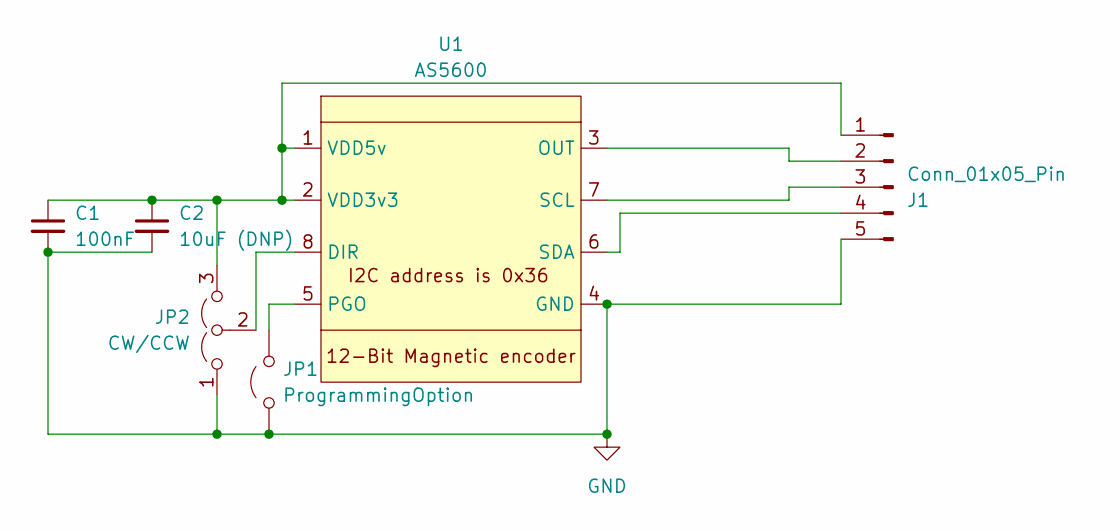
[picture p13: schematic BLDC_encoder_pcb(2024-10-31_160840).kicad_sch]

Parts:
C1: 100nF; C_0402_1005Metric_Pad0.74x0.62mm_HandSolder
C2: 10uF (DNP); C_0603_1608Metric_Pad1.08x0.95mm_HandSolder
J1: Conn_01x05_Pin; Microbot_BLDC_encoder
JP1: ProgrammingOption; SolderJumper-2_P1.3mm_Open_RoundedPad1.0x1.5mm
JP2: CW/CCW; SolderJumper-3_P1.3mm_Open_RoundedPad1.0x1.5mm_NumberLabels
U1: AS5600; SOIC-8_3.9x4.9mm_P1.27mm

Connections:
GND: C1.2, C2.2, J1.5, JP1.1 (A), JP2.1 (A), U1.4 (GND)
unnamed: C1.1, C2.1, J1.1, JP2.3 (B), U1.1 (VDD5v), U1.2 (VDD3v3)
unnamed: J1.2, U1.3 (OUT)
unnamed: J1.3, U1.7 (SCL)
unnamed: J1.4, U1.6 (SDA)
unnamed: JP1.2 (B), U1.5 (PGO)
unnamed: JP2.2 (C), U1.8 (DIR)

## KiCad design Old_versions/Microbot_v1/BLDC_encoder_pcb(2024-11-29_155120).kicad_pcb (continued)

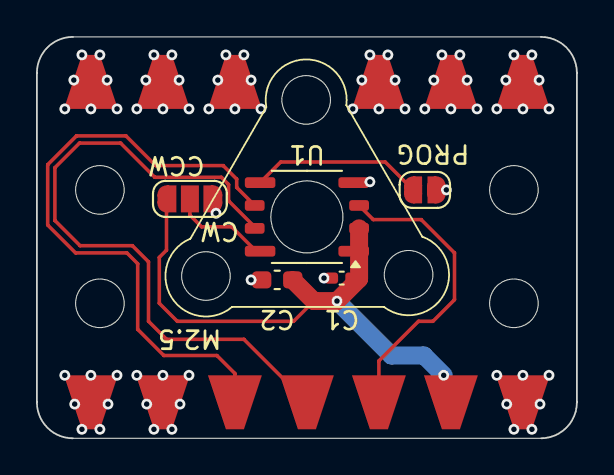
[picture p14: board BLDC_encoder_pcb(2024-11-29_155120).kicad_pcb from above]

Board: 2 copper layers, 30.0 x 22.3 mm, 6 parts (0 on the bottom side), 7 nets.

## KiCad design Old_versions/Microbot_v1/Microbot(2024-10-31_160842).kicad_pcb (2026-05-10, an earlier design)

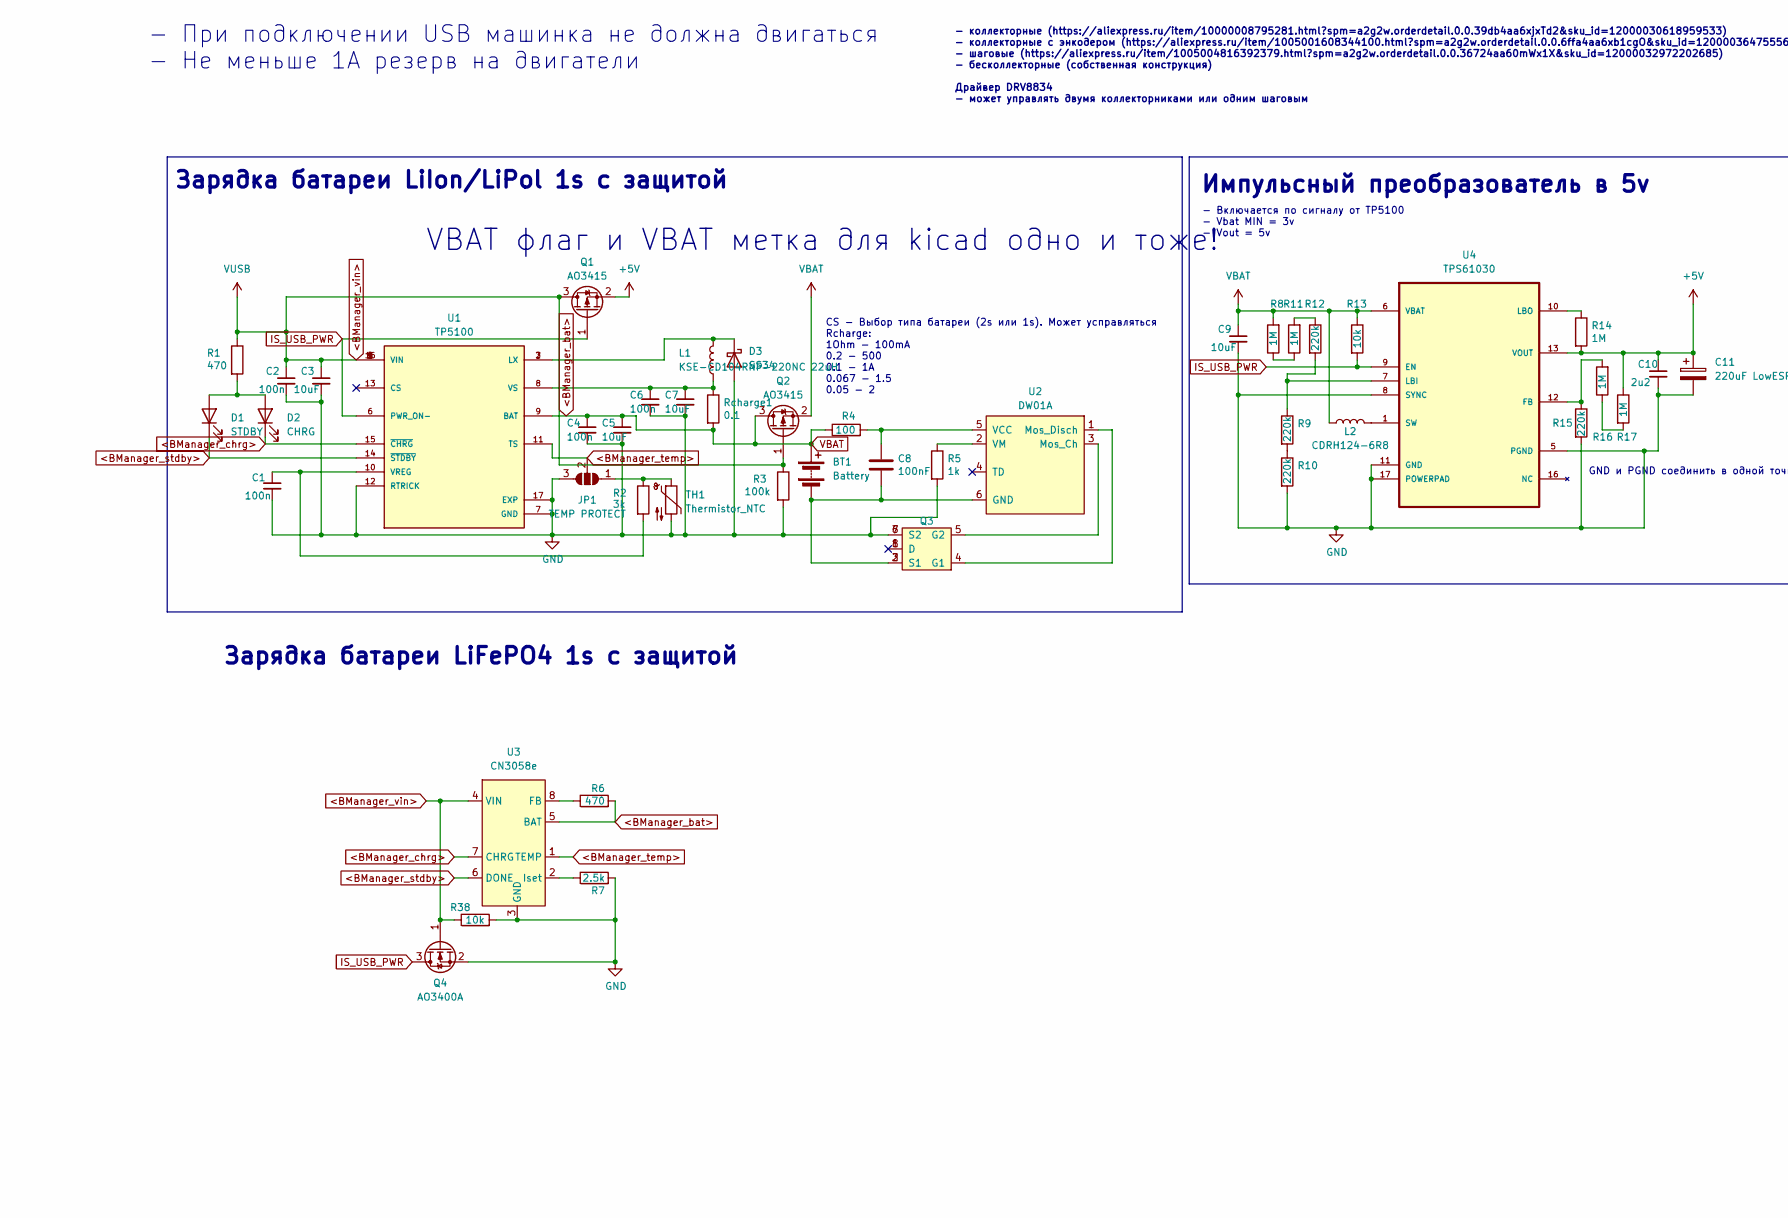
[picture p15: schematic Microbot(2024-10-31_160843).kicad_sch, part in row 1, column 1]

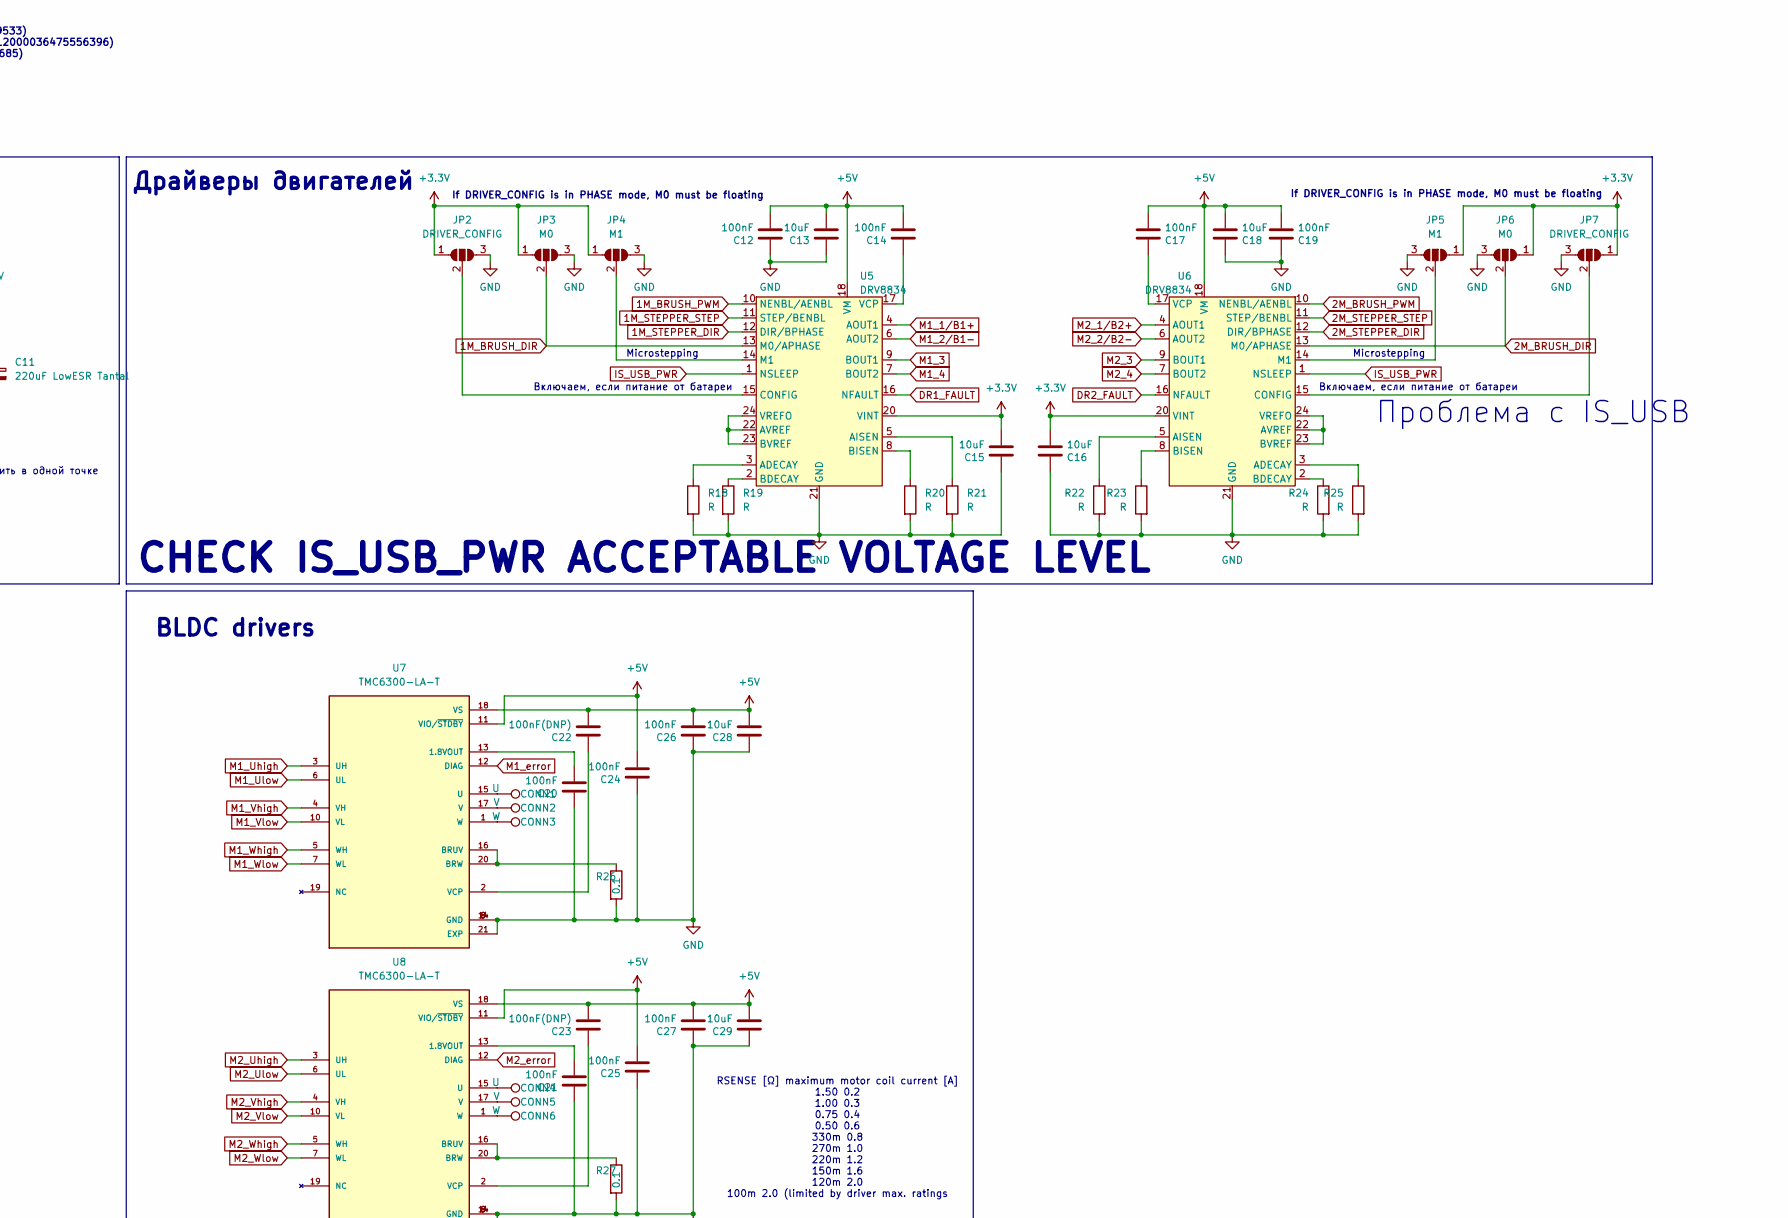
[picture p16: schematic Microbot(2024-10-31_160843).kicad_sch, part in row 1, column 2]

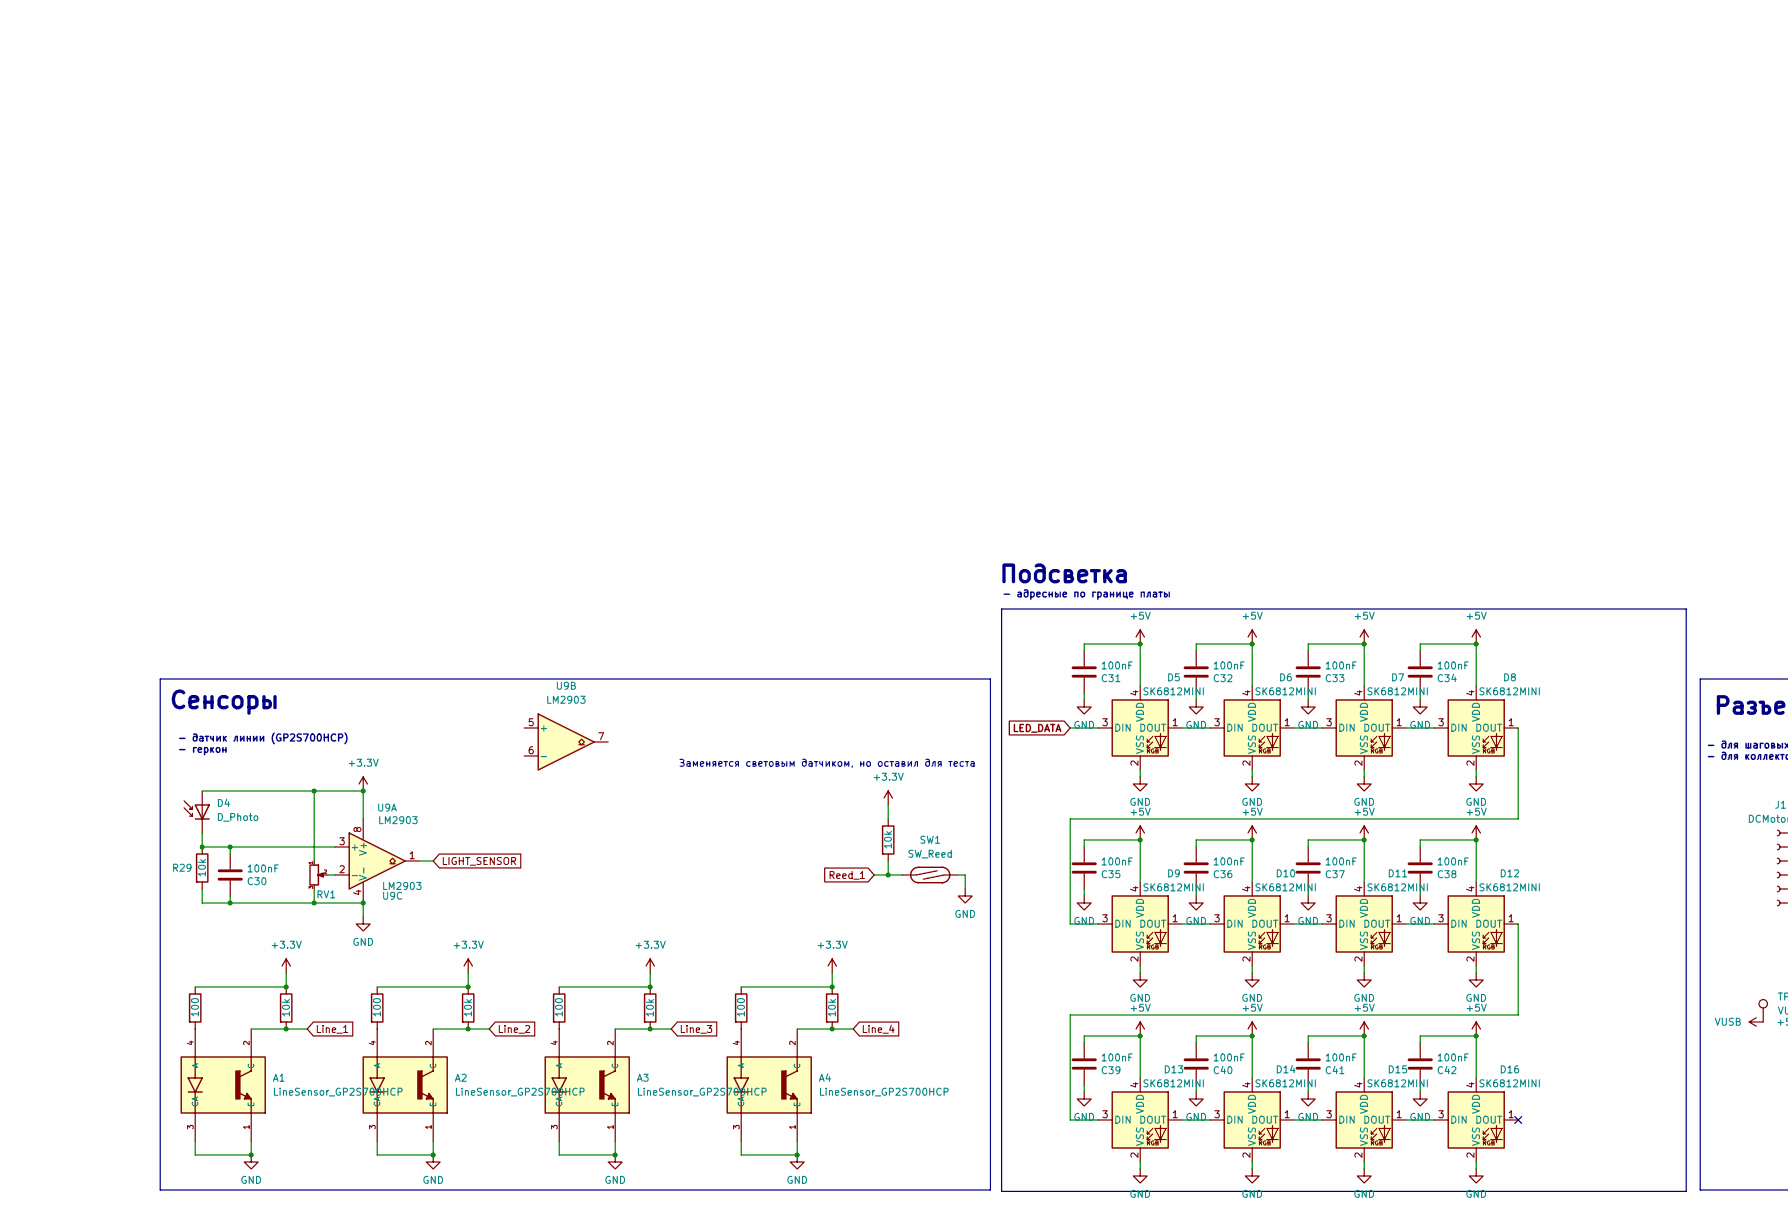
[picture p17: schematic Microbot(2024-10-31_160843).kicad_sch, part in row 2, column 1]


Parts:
A1, A2, A3, A4: LineSensor_GP2S700HCP; GP2S700HCP; PARTREV Oct. 3. 2005
BT1: Battery; Conn_BAT_18650_LowProfile
C1, C2, C4, C6: 100n; C_0402_1005Metric_Pad0.74x0.62mm_HandSolder
C3, C5, C7, C9, C13, C15, C16, C18, C28, C29: 10uF; C_0603_1608Metric_Pad1.08x0.95mm_HandSolder
C8, C12, C14, C17, C19, C20, C21, C24, C25, C26, C27, C30, C31, C32, C33, C34, C35, C36, C37, C38, C39, C40, C41, C42: 100nF; C_0402_1005Metric_Pad0.74x0.62mm_HandSolder
C10: 2u2; C_0603_1608Metric_Pad1.08x0.95mm_HandSolder
C11: 220uF LowESR Tantal; CP_EIA-7343-31_Kemet-D
C22, C23: 100nF(DNP); C_0402_1005Metric_Pad0.74x0.62mm_HandSolder
CONN1, CONN4: U; TestPoint_Pad_D1.5mm
CONN2, CONN5: V; TestPoint_Pad_D1.5mm
CONN3, CONN6: W; TestPoint_Pad_D1.5mm
D1: STDBY; LED_0603_1608Metric
D2: CHRG; LED_0603_1608Metric
D3: SS34; D_SMA-SMB_Universal_Handsoldering
D4: D_Photo; R_LDR_5.1x4.3mm_P3.4mm_Vertical
D5, D6, D7, D8, D9, D10, D11, D12, D13, D14, D15, D16: SK6812MINI; LED_SK6812MINI_PLCC4_3.5x3.5mm_P1.75mm
J1: DCMotor_left; JST_ZH_B6B-ZR-SM4-TF_1x06-1MP_P1.50mm_Vertical
J2: DCMotor_right; JST_ZH_B6B-ZR-SM4-TF_1x06-1MP_P1.50mm_Vertical
J3: STEPPERMotor_left; JST_PH_S4B-PH-SM4-TB_1x04-1MP_P2.00mm_Horizontal
J4: STEPPERMotor_right; JST_PH_S4B-PH-SM4-TB_1x04-1MP_P2.00mm_Horizontal
J5: BRUSH&STEPER_motors; PinHeader_2x08_P2.54mm_Vertical_SMD
J6: Sensors; PinHeader_2x05_P2.54mm_Vertical_SMD
J7: POWER; PinHeader_2x03_P2.54mm_Vertical_SMD
J8: BRUSHLESS_motors; PinHeader_2x07_P2.54mm_Vertical_SMD
JP1: TEMP PROTECT; SolderJumper-3_P1.3mm_Open_RoundedPad1.0x1.5mm
JP2, JP7: DRIVER_CONFIG; SolderJumper-3_P1.3mm_Open_RoundedPad1.0x1.5mm
JP3, JP6: M0; SolderJumper-3_P1.3mm_Open_RoundedPad1.0x1.5mm
JP4, JP5: M1; SolderJumper-3_P1.3mm_Open_RoundedPad1.0x1.5mm
L1: KSE-CD104RNP-220NC 22uH; L_10.4x10.4_H4.8
L2: CDRH124-6R8; L_12x12mm_H4.5mm
Q1, Q2: AO3415; SOT-23
Q3: 8205(Dual_Mosfet); SOT-23-6
Q4: AO3400A; SOT-23
R1, R6: 470; R_0402_1005Metric_Pad0.72x0.64mm_HandSolder
R2: 3k; R_0603_1608Metric
R3: 100k; R_0402_1005Metric_Pad0.72x0.64mm_HandSolder
R4: 100; R_0402_1005Metric_Pad0.72x0.64mm_HandSolder
R5: 1k; R_0402_1005Metric_Pad0.72x0.64mm_HandSolder
R7: 2.5k; R_0805_2012Metric_Pad1.20x1.40mm_HandSolder
R8, R11, R14, R16, R17: 1M; R_0402_1005Metric_Pad0.72x0.64mm_HandSolder
R9, R10, R12, R15: 220k; R_0402_1005Metric_Pad0.72x0.64mm_HandSolder
R13, R29, R30, R32, R34, R36, R37, R38: 10k; R_0402_1005Metric_Pad0.72x0.64mm_HandSolder
R18, R19, R20, R21, R22, R23, R24, R25: R; R_0805_2012Metric_Pad1.20x1.40mm_HandSolder
R26, R27: 0.1; R_0805_2012Metric_Pad1.20x1.40mm_HandSolder
R28, R31, R33, R35: 100; R_0805_2012Metric_Pad1.20x1.40mm_HandSolder
RV1: R_Potentiometer_Small; POT_SMD_3x3mm
Rcharge1: 0.1; R_1206_3216Metric_Pad1.30x1.75mm_HandSolder
SW1: SW_Reed; Reed_MKA10110
TH1: Thermistor_NTC; R_Axial_DIN0204_L3.6mm_D1.6mm_P7.62mm_Horizontal
TP2: VUSB; TestPoint_Pad_D2.0mm
TP3: +5V; TestPoint_Pad_D2.0mm
TP4: GND; TestPoint_Pad_D2.0mm
TP5: BAT; TestPoint_Pad_D2.0mm
TP6: IS_USB_PWR; TestPoint_Pad_D2.0mm
TP7: LightSensor; TestPoint_Pad_D2.0mm
U1: TP5100; QFN-16-1EP_4x4mm_P0.65mm_EP2.1x2.1mm; PARTREV 2.3
U2: DW01A; SOT-23-6_Handsoldering
U3: CN3058e; SOP-8_3.9x4.9mm_P1.27mm
U4: TPS61030; HTSSOP-16-1EP_4.4x5mm_P0.65mm_EP3x3mm; MPN TPS61030
U5, U6: DRV8834; HTSSOP-24-1EP_4.4x7.8mm_P0.65mm_EP3.4x7.8mm_Mask2.4x2.98mm
U7, U8: TMC6300-LA-T; TMC6300; PARTREV 1.08
U9: LM2903; SOIC-8_3.9x4.9mm_P1.27mm

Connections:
1M_BRUSH_DIR: J5.5, JP3.2 (C), U5.13 (M0/APHASE)
1M_BRUSH_PWM: J5.3, U5.10 (NENBL/AENBL)
1M_STEPPER_DIR: J5.9, U5.12 (DIR/BPHASE)
1M_STEPPER_STEP: J5.7, U5.11 (STEP/BENBL)
2M_BRUSH_DIR: J5.6, JP6.2 (C), U6.13 (M0/APHASE)
2M_BRUSH_PWM: J5.4, U6.10 (NENBL/AENBL)
2M_STEPPER_DIR: J5.10, U6.12 (DIR/BPHASE)
2M_STEPPER_STEP: J5.8, U6.11 (STEP/BENBL)
+3.3V: C15.2, C16.2, D4.2 (A), J1.5, J2.5, J5.1, JP2.1 (A), JP3.1 (A), JP4.1 (A), JP5.1 (A), JP6.1 (A), JP7.1 (A), R28.1, R30.1, R31.1, R32.1, R33.1, R34.1, R35.1, R36.1, R37.1, RV1.1, U5.20 (VINT), U6.20 (VINT), U9.8 (V+)
+5V: C10.1, C11.1, C12.2, C13.2, C14.2, C17.2, C18.2, C19.2, C22.2, C23.2, C24.2, C25.2, C26.2, C27.2, C28.2, C29.2, C31.2, C32.2, C33.2, C34.2, C35.2, C36.2, C37.2, C38.2, C39.2, C40.2, C41.2, C42.2, D5.4 (VDD), D6.4 (VDD), D7.4 (VDD), D8.4 (VDD), D9.4 (VDD), D10.4 (VDD), D11.4 (VDD), D12.4 (VDD), D13.4 (VDD), D14.4 (VDD), D15.4 (VDD), D16.4 (VDD), J7.3, J7.4, Q1.2 (S), R14.2, R17.1, TP3.1, U4.13 (VOUT), U4.14 (VOUT_2), U4.15 (VOUT_3), U5.18 (VM), U5.19 (VM), U6.18 (VM), U6.19 (VM), U7.11 (VIO/~STDBY), U7.18 (VS), U8.11 (VIO/~STDBY), U8.18 (VS)
<BManager_bat>: BT1.1 (+), C4.1, C5.1, C9.1, J6.1, L2.1, Q2.2 (S), Q2.3 (D), R4.1, R6.2, R8.2, R13.1, Rcharge1.2, TP5.1, U1.9 (BAT), U3.5 (BAT), U4.6 (VBAT)
<BManager_chrg>: D2.1 (K), U1.15 (~CHRG), U3.7 (CHRG)
<BManager_stdby>: D1.1 (K), U1.14 (~STDBY), U3.6 (DONE)
<BManager_temp>: JP1.2 (C), U1.11 (TS), U3.1 (TEMP)
<BManager_vin>: C2.1, C3.1, J7.1, J7.2, Q1.3 (D), Q2.1 (G), Q4.1 (G), R1.1, R3.1, R38.1, TP2.1, U1.1 (VIN), U1.4 (VIN), U1.5 (VIN), U1.16 (VIN), U3.4 (VIN)
DR1_FAULT: J5.15, U5.16 (NFAULT)
DR2_FAULT: J5.16, U6.16 (NFAULT)
GND: A1.1 (E), A1.3 (CA), A2.1 (E), A2.3 (CA), A3.1 (E), A3.3 (CA), A4.1 (E), A4.3 (CA), C1.2, C2.2, C3.2, C4.2, C5.2, C6.2, C7.2, C9.2, C10.2, C11.2, C12.1, C13.1, C15.1, C16.1, C18.1, C19.1, C20.1, C21.1, C24.1, C25.1, C26.1, C27.1, C28.1, C29.1, C30.1, C31.1, C32.1, C33.1, C34.1, C35.1, C36.1, C37.1, C38.1, C39.1, C40.1, C41.1, C42.1, D3.2 (A), D5.2 (VSS), D6.2 (VSS), D7.2 (VSS), D8.2 (VSS), D9.2 (VSS), D10.2 (VSS), D11.2 (VSS), D12.2 (VSS), D13.2 (VSS), D14.2 (VSS), D15.2 (VSS), D16.2 (VSS), J1.2, J2.2, J5.2, J6.10, J7.5, J7.6, JP1.3 (B), JP2.3 (B), JP3.3 (B), JP4.3 (B), JP5.3 (B), JP6.3 (B), JP7.3 (B), Q3.6 (S2), Q3.7 (S2), Q4.2 (S), R3.2, R5.2, R7.2, R10.2, R15.2, R18.2, R19.2, R20.2, R21.2, R22.2, R23.2, R24.2, R25.2, R26.2, R27.2, R29.2, R38.2, RV1.3, SW1.2, TH1.2, TP4.1, U1.7 (GND), U1.12 (RTRICK), U1.17 (EXP), U3.3 (GND), U4.3 (PGND_2), U4.4 (PGND_3), U4.5 (PGND), U4.8 (SYNC), U4.11 (GND), U4.17 (POWERPAD), U5.21 (GND), U6.21 (GND), U7.8 (GND), U7.9 (GND), U7.14 (GND), U7.21 (EXP), U8.8 (GND), U8.9 (GND), U8.14 (GND), U8.21 (EXP), U9.4 (V-)
HALL_left_A: J1.4, J5.11
HALL_left_B: J1.3, J5.13
HALL_right_A: J2.4, J5.12
HALL_right_B: J2.3, J5.14
IS_USB_PWR: J6.8, Q1.1 (G), Q4.3 (D), R13.2, TP6.1, U1.6 (PWR_ON-), U4.9 (EN), U5.1 (NSLEEP), U6.1 (NSLEEP)
LED_DATA: D5.3 (DIN), J6.9
Line_1: A1.2 (C), J6.2, R30.2
Line_2: A2.2 (C), J6.3, R32.2
Line_3: A3.2 (C), J6.4, R34.2
Line_4: A4.2 (C), J6.5, R36.2
M1_1/B1+: J1.6, J3.4, U5.4 (AOUT1)
M1_2/B1-: J1.1, J3.3, U5.6 (AOUT2)
M1_3: J3.2, U5.9 (BOUT1)
M1_4: J3.1, U5.7 (BOUT2)
M1_Uhigh: J8.1, U7.3 (UH)
M1_Ulow: J8.2, U7.6 (UL)
M1_Vhigh: J8.3, U7.4 (VH)
M1_Vlow: J8.4, U7.10 (VL)
M1_Whigh: J8.5, U7.5 (WH)
M1_Wlow: J8.6, U7.7 (WL)
M1_error: J8.7, U7.12 (DIAG)
M2_1/B2+: J2.6, J4.4, U6.4 (AOUT1)
M2_2/B2-: J2.1, J4.3, U6.6 (AOUT2)
M2_3: J4.2, U6.9 (BOUT1)
M2_4: J4.1, U6.7 (BOUT2)
M2_Uhigh: J8.9, U8.3 (UH)
M2_Ulow: J8.10, U8.6 (UL)
M2_Vhigh: J8.11, U8.4 (VH)
M2_Vlow: J8.12, U8.10 (VL)
M2_Whigh: J8.13, U8.5 (WH)
M2_Wlow: J8.14, U8.7 (WL)
M2_error: J8.8, U8.12 (DIAG)
unnamed: A1.4 (A), R28.2
unnamed: A2.4 (A), R31.2
unnamed: A3.4 (A), R33.2
unnamed: A4.4 (A), R35.2
unnamed: BT1.2 (-), C8.2, Q3.2 (S1), Q3.3 (S1), U2.6 (GND)
unnamed: D1.2 (A), D2.2 (A), R1.2
unnamed: D3.1 (K), L1.2, U1.2 (LX), U1.3 (LX)
unnamed: C30.2, D4.1 (K), R29.1, U9.3 (+)
unnamed: D5.1 (DOUT), D6.3 (DIN)
unnamed: D6.1 (DOUT), D7.3 (DIN)
unnamed: D7.1 (DOUT), D8.3 (DIN)
unnamed: D8.1 (DOUT), D9.3 (DIN)
unnamed: D9.1 (DOUT), D10.3 (DIN)
unnamed: D10.1 (DOUT), D11.3 (DIN)
unnamed: D11.1 (DOUT), D12.3 (DIN)
unnamed: D12.1 (DOUT), D13.3 (DIN)
unnamed: D13.1 (DOUT), D14.3 (DIN)
unnamed: D14.1 (DOUT), D15.3 (DIN)
unnamed: D15.1 (DOUT), D16.3 (DIN)
unnamed: JP1.1 (A), R2.1, TH1.1
unnamed: JP2.2 (C), U5.15 (CONFIG)
unnamed: JP4.2 (C), U5.14 (M1)
unnamed: JP5.2 (C), U6.14 (M1)
unnamed: JP7.2 (C), U6.15 (CONFIG)
unnamed: L2.2, U4.1 (SW), U4.2 (SW)
unnamed: Q3.4 (G1), U2.1 (Mos_Disch)
unnamed: Q3.5 (G2), U2.3 (Mos_Ch)
unnamed: R9.2, R10.1
unnamed: R8.1, R11.1
unnamed: R11.2, R12.1
unnamed: R16.1, R17.2
unnamed: C1.1, R2.2, U1.10 (VREG)
unnamed: C6.1, C7.1, L1.1, Rcharge1.1, U1.8 (VS)
unnamed: C8.1, R4.2, U2.5 (VCC)
unnamed: R5.1, U2.2 (VM)
unnamed: R6.1, U3.8 (FB)
unnamed: R7.1, U3.2 (Iset)
unnamed: R15.1, R16.2, U4.12 (FB)
unnamed: R9.1, R12.2, U4.7 (LBI)
unnamed: R14.1, U4.10 (LBO)
unnamed: R18.1, U5.3 (ADECAY)
unnamed: R21.1, U5.5 (AISEN)
unnamed: U5.22 (AVREF), U5.23 (BVREF), U5.24 (VREFO)
unnamed: R19.1, U5.2 (BDECAY)
unnamed: R20.1, U5.8 (BISEN)
unnamed: C14.1, U5.17 (VCP)
unnamed: R25.1, U6.3 (ADECAY)
unnamed: R22.1, U6.5 (AISEN)
unnamed: U6.22 (AVREF), U6.23 (BVREF), U6.24 (VREFO)
unnamed: R24.1, U6.2 (BDECAY)
unnamed: R23.1, U6.8 (BISEN)
unnamed: C17.1, U6.17 (VCP)
unnamed: C20.2, U7.13 (1.8VOUT)
unnamed: R26.1, U7.16 (BRUV), U7.20 (BRW)
unnamed: CONN1.1, U7.15 (U)
unnamed: CONN2.1, U7.17 (V)
unnamed: C22.1, U7.2 (VCP)
unnamed: CONN3.1, U7.1 (W)
unnamed: C21.2, U8.13 (1.8VOUT)
unnamed: R27.1, U8.16 (BRUV), U8.20 (BRW)
unnamed: CONN4.1, U8.15 (U)
unnamed: CONN5.1, U8.17 (V)
unnamed: C23.1, U8.2 (VCP)
unnamed: CONN6.1, U8.1 (W)
unnamed: RV1.2, U9.2 (-)

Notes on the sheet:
Импульсный преобразователь в 5v
Включаем, если питание от батареи
- для шаговых () PH 4P - для коллекторных с энкодером () PH 6P
Заменяется световым датчиком, но оставил для теста
Драйверы двигателей
- При подключении USB машинка не должна двигаться - Не меньше 1А резерв на двигатели
Разъемы
Зарядка батареи LiFePO4 1s с защитой
- Включается по сигналу от TP5100 - Vbat MIN = 3v - Vout = 5v
Проблема с IS_USB
If DRIVER_CONFIG is in PHASE mode, M0 must be floating
- адресные по границе платы
Подсветка
Зарядка батареи LiIon/LiPol 1s с защитой
- коллекторные (https://aliexpress.ru/item/10000008795281.html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) - коллекторные с энкодером (https://aliexpress.ru/item/1005001608344100.html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) - шаговые (https://aliexp…
CHECK IS_USB_PWR ACCEPTABLE VOLTAGE LEVEL
- датчик линии (GP2S700HCP) - геркон
Сенсоры
Microstepping
VBAT флаг и VBAT метка для kicad одно и тоже!
CS - Выбор типа батареи (2s или 1s). Может усправляться Rcharge: 1Ohm - 100mA 0.2 - 500 0.1 - 1A 0.067 - 1.5 0.05 - 2
GND и PGND соединить в одной точке
RSENSE [Ω] maximum motor coil current [A] 1.50 0.2 1.00 0.3 0.75 0.4 0.50 0.6 330m 0.8 270m 1.0 220m 1.2 150m 1.6 120m 2.0 100m 2.0 (limited by driver max. ratings
BLDC drivers

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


Board: 4 copper layers, 90.0 x 110.0 mm, 150 parts (5 on the bottom side), 117 nets.

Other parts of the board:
Ref**: Val**; Microbot_Silk_TOP_1
Ref**#2: Val**; Microbot_Silk_BOTTOM
TP7#2: LightSensor; TestPoint_Pad_D2.0mm

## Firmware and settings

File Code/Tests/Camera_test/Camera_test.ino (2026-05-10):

#include "esp_camera.h"
#include <WiFi.h>
#include <Preferences.h>

#define PWDN_GPIO_NUM     -1
#define RESET_GPIO_NUM    -1
#define XCLK_GPIO_NUM     5
#define Y9_GPIO_NUM       4
#define Y8_GPIO_NUM       6
#define Y7_GPIO_NUM       7
#define Y6_GPIO_NUM       14
#define Y5_GPIO_NUM       17
#define Y4_GPIO_NUM       21
#define Y3_GPIO_NUM       18
#define Y2_GPIO_NUM       16
#define VSYNC_GPIO_NUM    1
#define HREF_GPIO_NUM     2
#define PCLK_GPIO_NUM     15
#define SIOD_GPIO_NUM     8
#define SIOC_GPIO_NUM     9

#define LED_GPIO_NUM  47

Preferences preferences;
const char* ssid = "";
const char* password = "";

void startCameraServer();
void setupLedFlash(int pin);

void connectToWiFi(const char* ssid, const char* password) {
  WiFi.begin(ssid, password);
  Serial.printf("Connecting to WiFi: %s\n", ssid);
  int retries = 0;
  while (WiFi.status() != WL_CONNECTED && retries < 20) {
    delay(500);
    Serial.print(".");
    retries++;
  }

  if (WiFi.status() == WL_CONNECTED) {
    Serial.println("\nWiFi connected!");
    Serial.print("IP address: ");
    Serial.println(WiFi.localIP());
  } else {
    Serial.println("\nFailed to connect to WiFi.");
  }
}

void initWiFi() {
  preferences.begin("wifi", false);
  String savedSSID = preferences.getString("ssid", "");
  String savedPASS = preferences.getString("password", "");

  if (savedSSID.length() > 0 && savedPASS.length() > 0) {
    Serial.println("Found saved WiFi credentials.");
    connectToWiFi(savedSSID.c_str(), savedPASS.c_str());

    if (WiFi.status() == WL_CONNECTED) {
      return;
    } else {
      Serial.println("Stored credentials failed. Please enter new credentials.");
    }
  } else {
    Serial.println("No WiFi credentials found. Please enter:");
  }

  while (Serial.available()) Serial.read();

  Serial.println("Enter SSID: ");
  while (Serial.available() == 0) delay(10);
  String inputSSID = Serial.readStringUntil('\n');
  inputSSID.trim();

  Serial.println("Enter Password: ");
  while (Serial.available() == 0) delay(10);
  String inputPASS = Serial.readStringUntil('\n');
  inputPASS.trim();

  connectToWiFi(inputSSID.c_str(), inputPASS.c_str());

  if (WiFi.status() == WL_CONNECTED) {
    preferences.putString("ssid", inputSSID);
    preferences.putString("password", inputPASS);
    Serial.println("WiFi credentials saved.");
  } else {
    Serial.println("Failed to connect. Credentials not saved.");
  }

  preferences.end();
}

void initCamera(){
  camera_config_t config;
  config.ledc_channel = LEDC_CHANNEL_0;
  config.ledc_timer = LEDC_TIMER_0;
  config.pin_d0 = Y2_GPIO_NUM;
  config.pin_d1 = Y3_GPIO_NUM;
  config.pin_d2 = Y4_GPIO_NUM;
  config.pin_d3 = Y5_GPIO_NUM;
  config.pin_d4 = Y6_GPIO_NUM;
  config.pin_d5 = Y7_GPIO_NUM;
  config.pin_d6 = Y8_GPIO_NUM;
  config.pin_d7 = Y9_GPIO_NUM;
  config.pin_xclk = XCLK_GPIO_NUM;
  config.pin_pclk = PCLK_GPIO_NUM;
  config.pin_vsync = VSYNC_GPIO_NUM;
  config.pin_href = HREF_GPIO_NUM;
  config.pin_sccb_sda = SIOD_GPIO_NUM;
  config.pin_sccb_scl = SIOC_GPIO_NUM;
  config.pin_pwdn = PWDN_GPIO_NUM;
  config.pin_reset = RESET_GPIO_NUM;
  config.xclk_freq_hz = 20000000;
  config.frame_size = FRAMESIZE_UXGA;
  config.pixel_format = PIXFORMAT_JPEG;  // for streaming
  //config.pixel_format = PIXFORMAT_RGB565; // for face detection/recognition
  config.grab_mode = CAMERA_GRAB_WHEN_EMPTY;
  config.fb_location = CAMERA_FB_IN_PSRAM;
  config.jpeg_quality = 12;
  config.fb_count = 1;

  // if PSRAM IC present, init with UXGA resolution and higher JPEG quality
  //                      for larger pre-allocated frame buffer.
  if (config.pixel_format == PIXFORMAT_JPEG) {
    if (psramFound()) {
      config.jpeg_quality = 10;
      config.fb_count = 2;
      config.grab_mode = CAMERA_GRAB_LATEST;
    } else {
      // Limit the frame size when PSRAM is not available
      config.frame_size = FRAMESIZE_SVGA;
      config.fb_location = CAMERA_FB_IN_DRAM;
    }
  } else {
    // Best option for face detection/recognition
    config.frame_size = FRAMESIZE_240X240;
  }

  // camera init
  esp_err_t err = esp_camera_init(&config);
  if (err != ESP_OK) {
    Serial.printf("Camera init failed with error 0x%x", err);
    return;
  }

  sensor_t *s = esp_camera_sensor_get();
  // initial sensors are flipped vertically and colors are a bit saturated
  if (s->id.PID == OV3660_PID) {
    s->set_vflip(s, 1);        // flip it back
    s->set_brightness(s, 1);   // up the brightness just a bit
    s->set_saturation(s, -2);  // lower the saturation
  }
  // drop down frame size for higher initial frame rate
  if (config.pixel_format == PIXFORMAT_JPEG) {
    s->set_framesize(s, FRAMESIZE_QVGA);
  }
}



void setup() {
  Serial.begin(115200);
  Serial.setDebugOutput(true);
  delay(1000);
  Serial.println();
  
  initCamera();
  setupLedFlash(LED_GPIO_NUM);
  initWiFi();
  startCameraServer();
}

void loop() {
  // Do nothing. Everything is done in another task by the web server
  delay(10000);
}
